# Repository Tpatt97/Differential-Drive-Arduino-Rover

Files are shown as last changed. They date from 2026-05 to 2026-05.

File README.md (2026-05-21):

# Differential-Drive-Arduino-Rover
Custom differential-drive rover featuring a fully 3D printed chassis, PWM motor control, joystick steering, and live OLED telemetry using Arduino.

Rover Demo

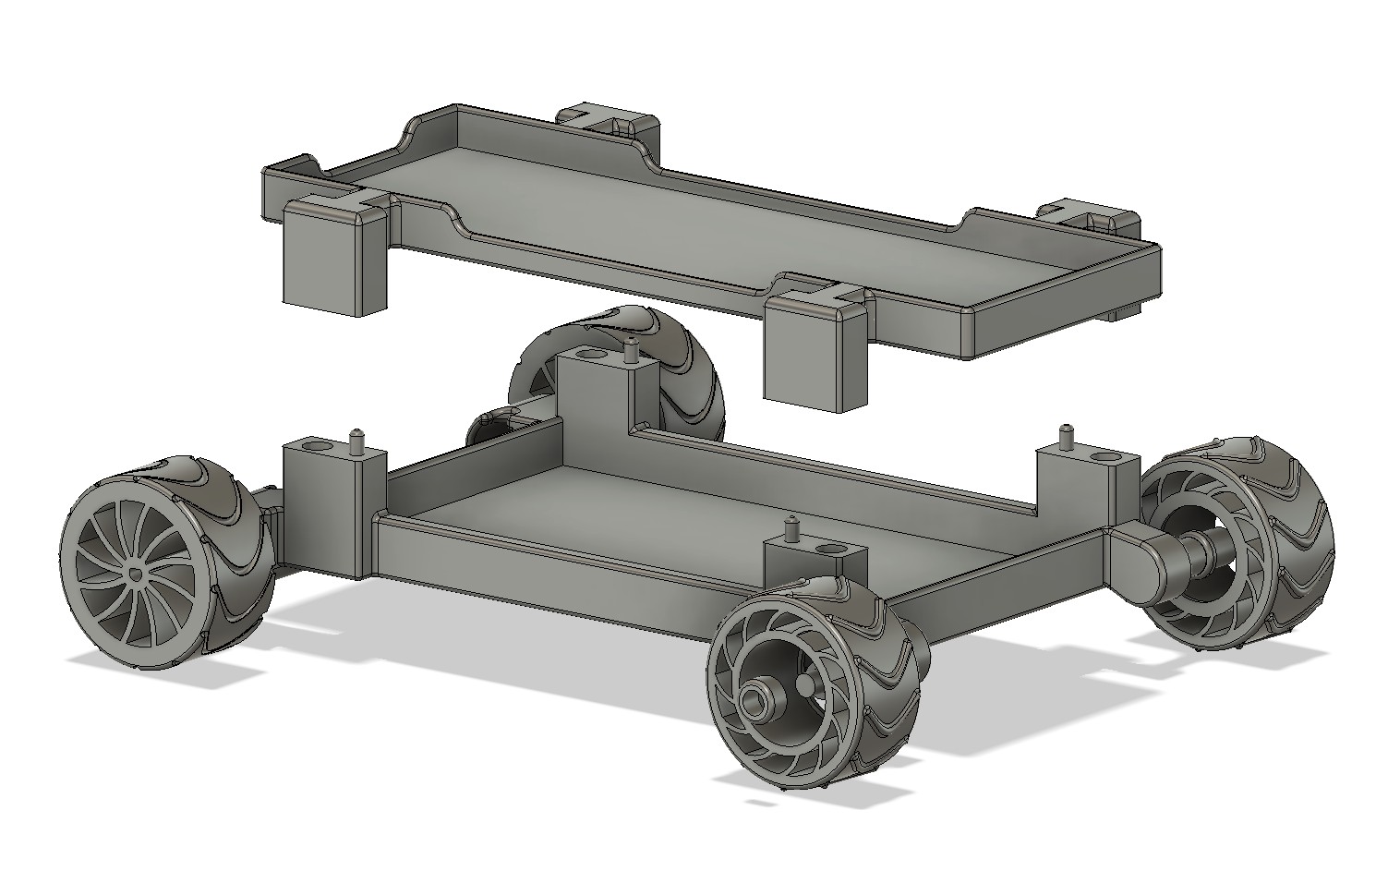
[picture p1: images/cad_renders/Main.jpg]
HERO Image


---

## Project Overview

This project is a custom-built Arduino rover platform designed and fabricated from the ground up using Fusion 360, embedded motor control, and additive manufacturing techniques.

The rover uses a differential steering drivetrain powered by dual DC gear motors controlled through PWM transistor stages. Real-time telemetry is displayed through an onboard I2C OLED display while joystick input provides proportional throttle and steering control.

Rover Demo

The project combines:

- Mechanical CAD design
- 3D printing
- Embedded systems
- Power electronics
- Differential drive control
- Real-time telemetry systems
  
---

## Features 

- Fully custom 3D printed chassis and drivetrain
- Differential steering control
- Dual PWM-controlled DC motors
- Analog joystick input system
- Live OLED telemetry display
- Custom Fusion 360 wheel and tread design
- Modular upper electronics tray
- Embedded Arduino firmware
- Real-time motor output calculations

---

## Media Section

### Final Rover Assembly
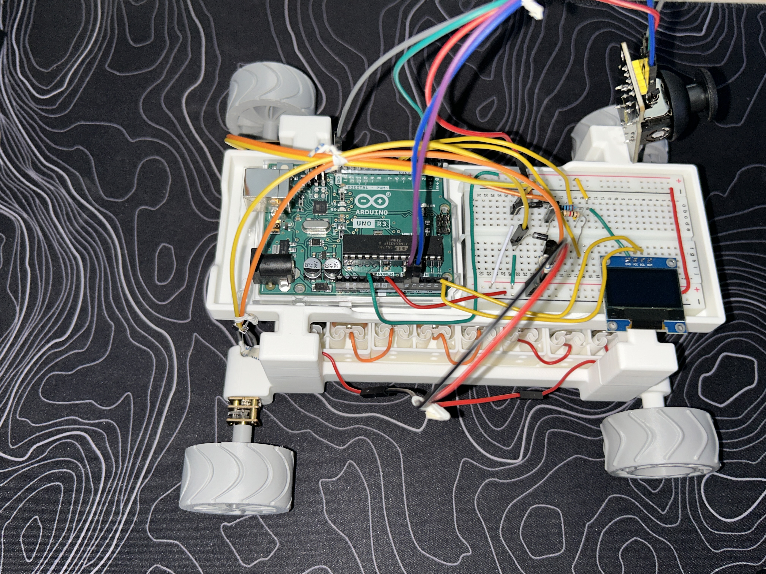
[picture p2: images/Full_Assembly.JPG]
Top View


### Lower Chassis
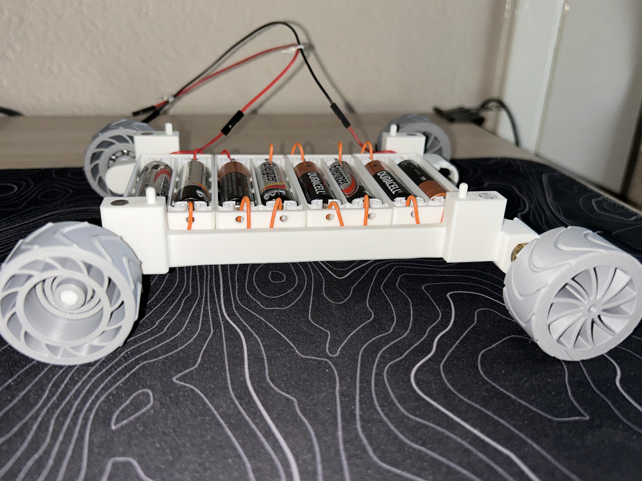
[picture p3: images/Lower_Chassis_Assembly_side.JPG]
Lower Chassis


### Upper Electronics Tray
Upper Electronics Tray

### Modular Assembly

- The upper electronics tray was designed as a removable modular assembly using alignment pins and recessed magnetic attachment points integrated directly into the lower chassis and upper tray. This architecture allowed rapid access to the battery bank while maintaining repeatable alignment and secure retention of the embedded electronics during both battery replacement and rover operation.
  
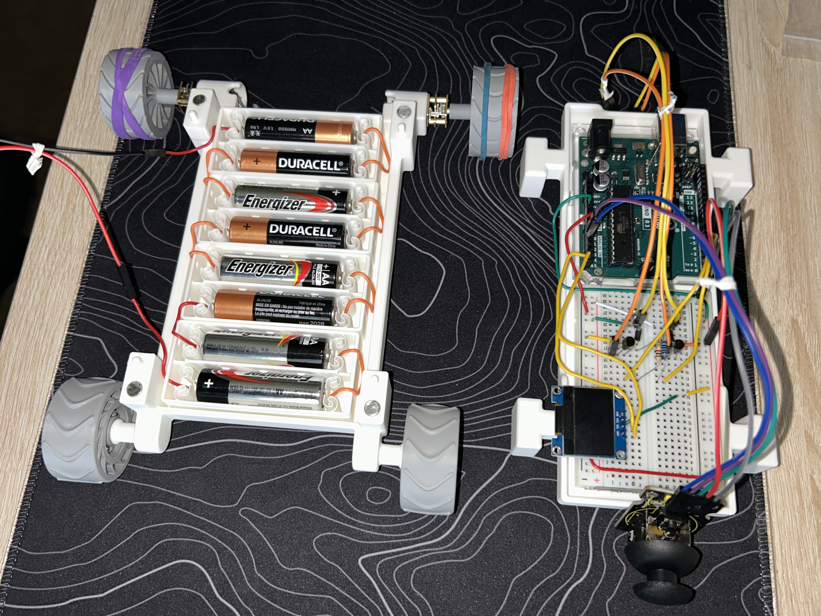
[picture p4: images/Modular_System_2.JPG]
Modular System


### OLED Telemetry
OLED Telemetry

### Drivetrain Closeup
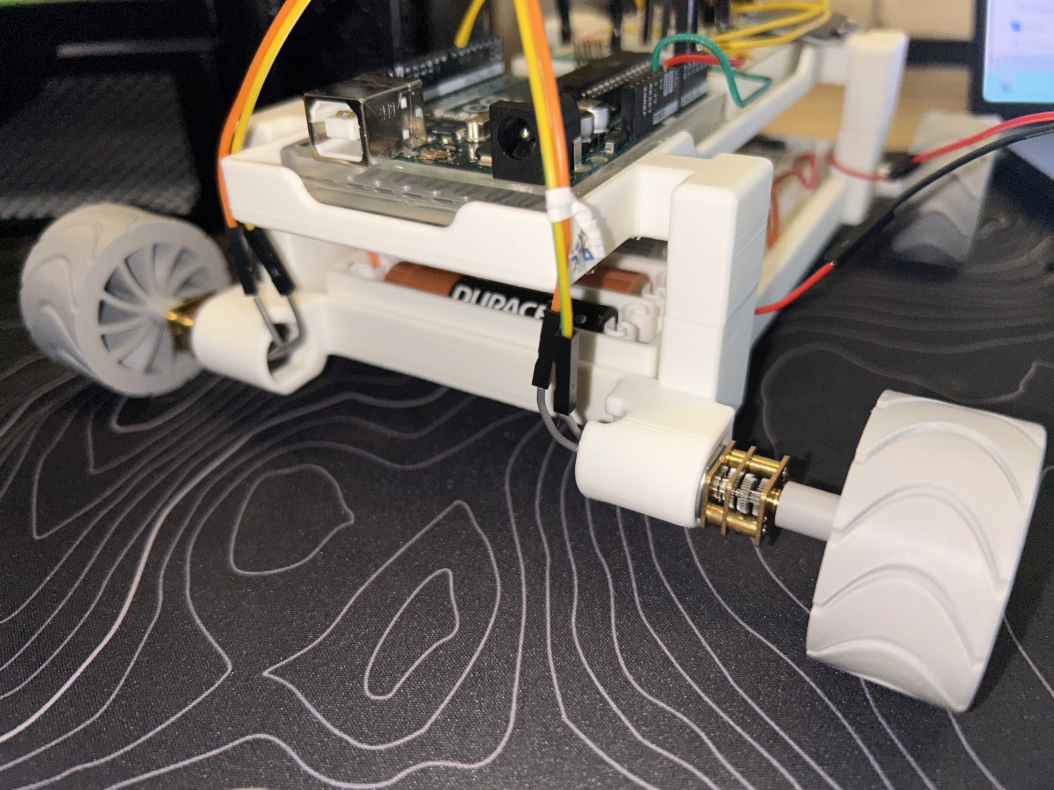
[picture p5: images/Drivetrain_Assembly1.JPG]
Wheel Closeup 1

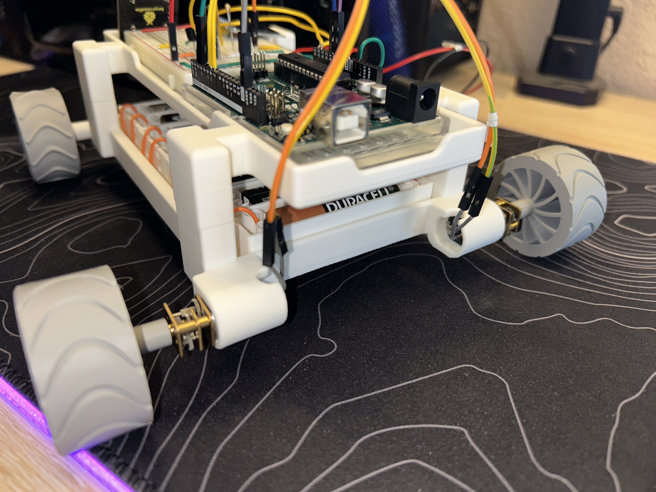
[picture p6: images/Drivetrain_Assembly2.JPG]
Wheel Closeup


---

## CAD Design Section

All mechanical components were designed in Autodesk Fusion 360.

Key design objectives included:

- Modular assembly
- Compact drivetrain packaging
- Easy battery integration
- Printable geometry optimization
- Lightweight wheel construction
- Integrated wiring/electronics tray

### Fusion 360 Renders

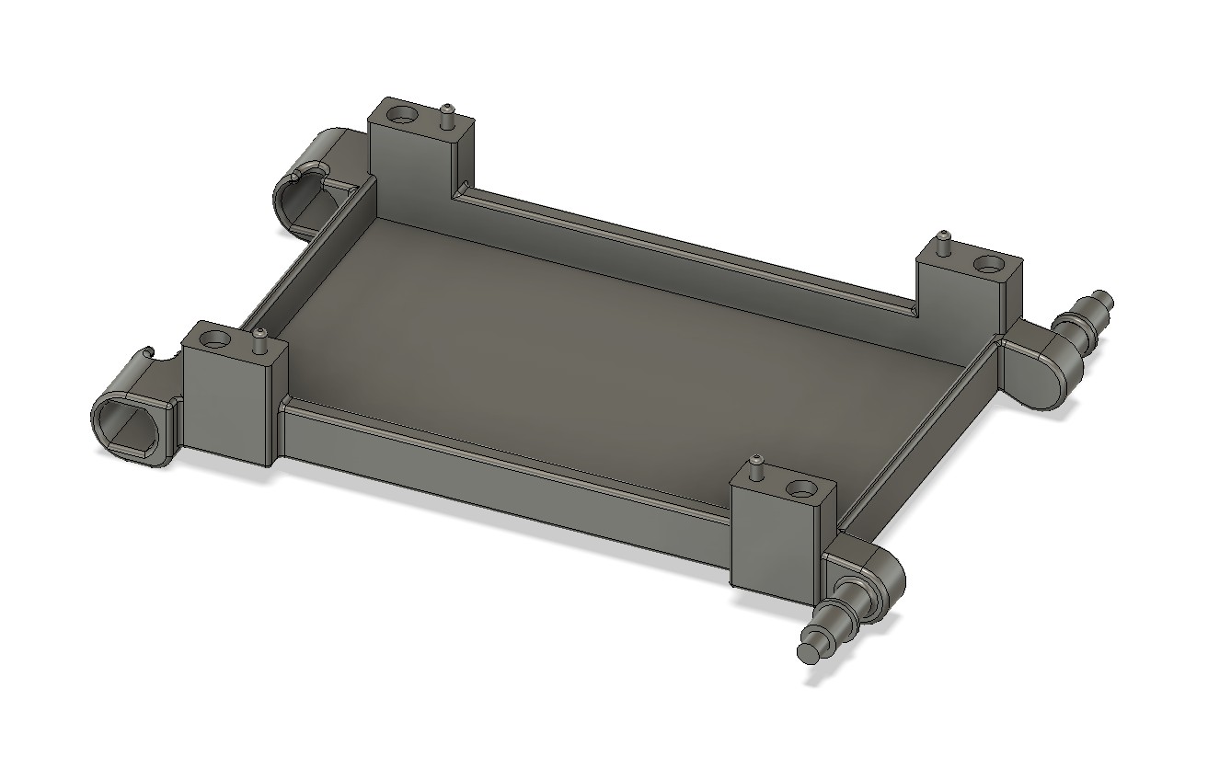
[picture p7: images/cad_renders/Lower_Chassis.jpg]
Lower Chassis


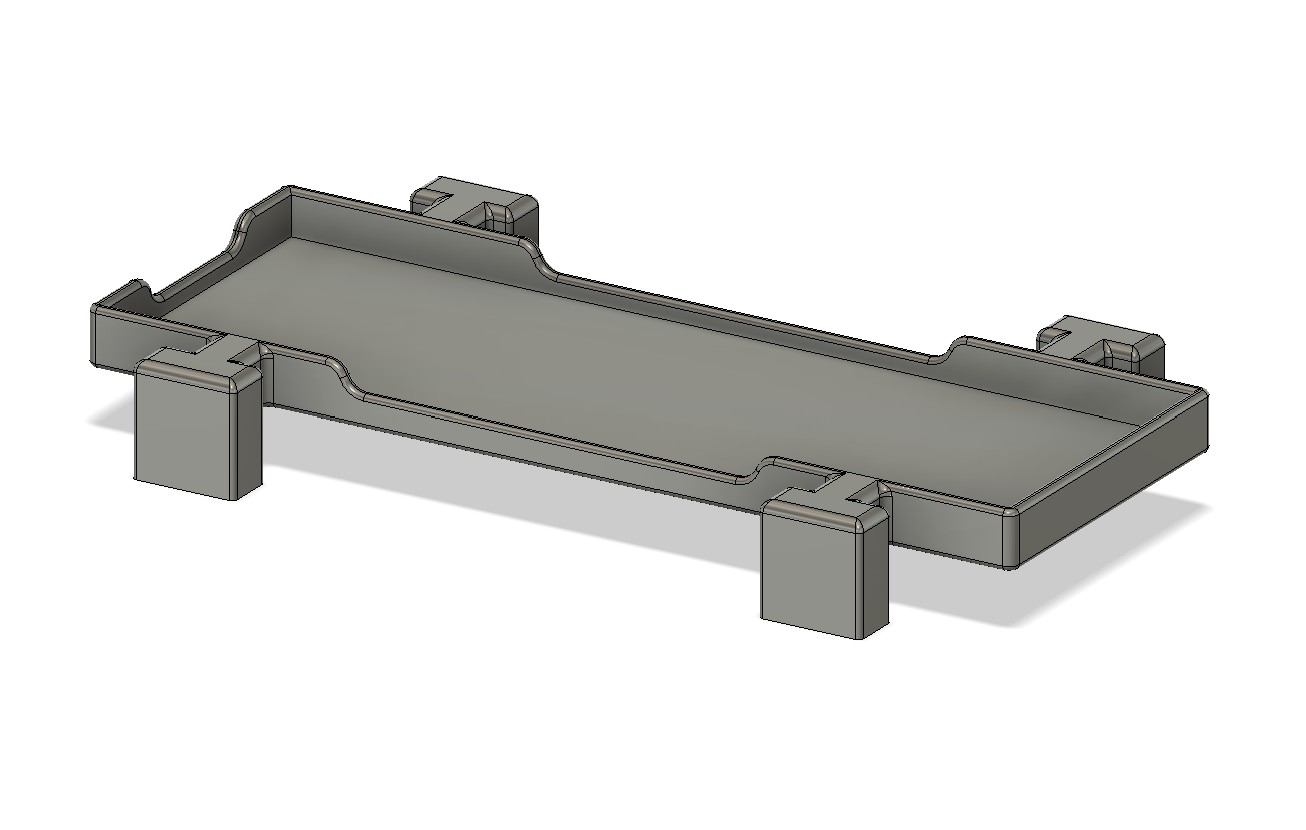
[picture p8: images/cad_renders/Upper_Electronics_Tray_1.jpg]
Upper Electroncis Tray 1


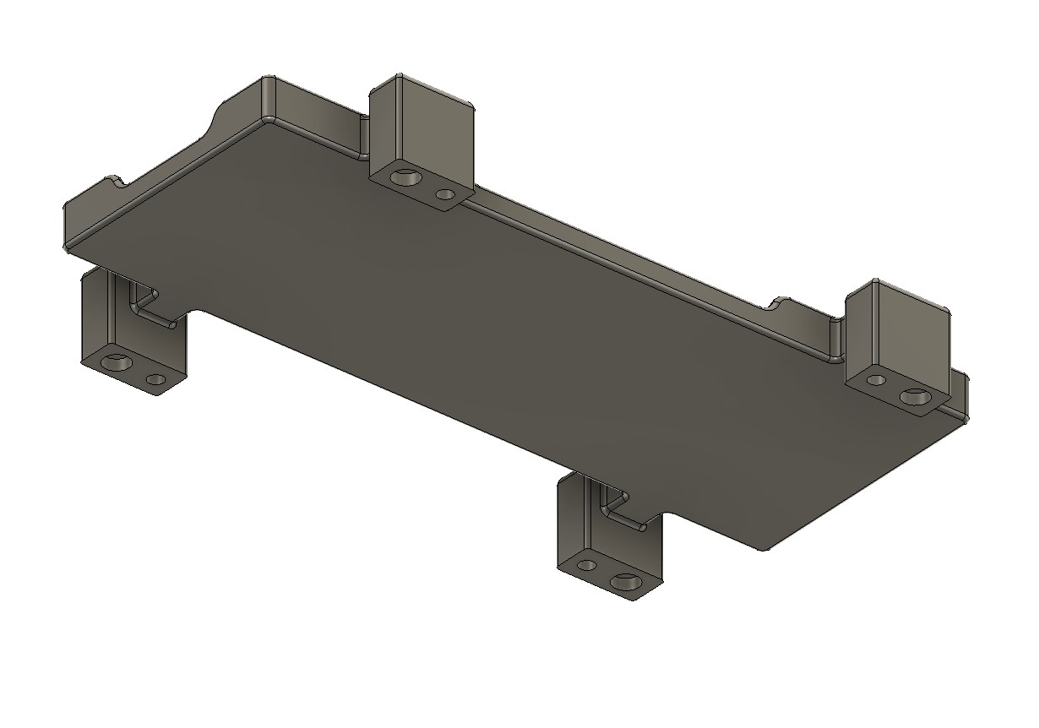
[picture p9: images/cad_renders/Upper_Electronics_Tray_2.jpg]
Upper Electroncis Tray 2


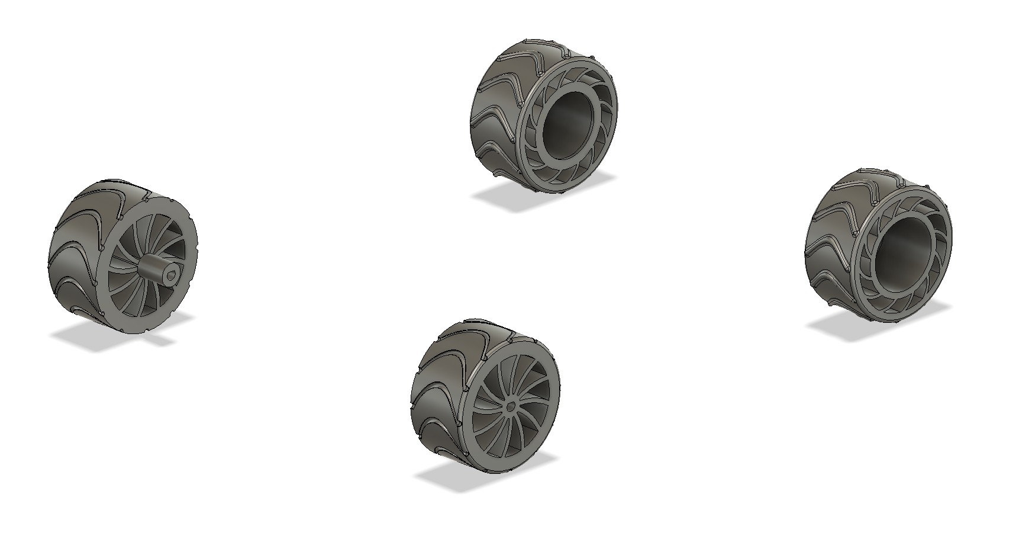
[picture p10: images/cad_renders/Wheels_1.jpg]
Wheel Design - All


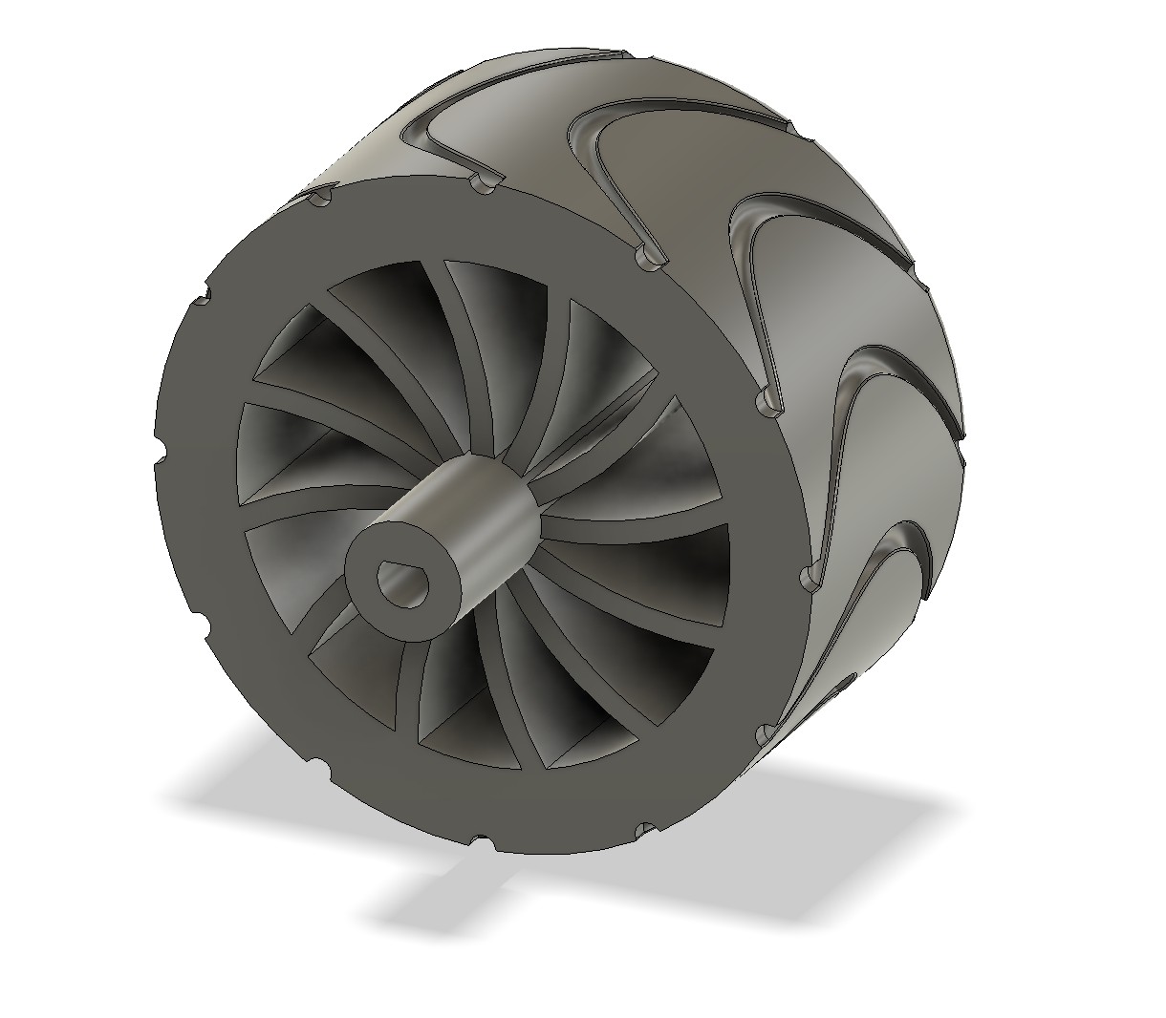
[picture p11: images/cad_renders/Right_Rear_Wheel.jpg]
Right Rear Wheel


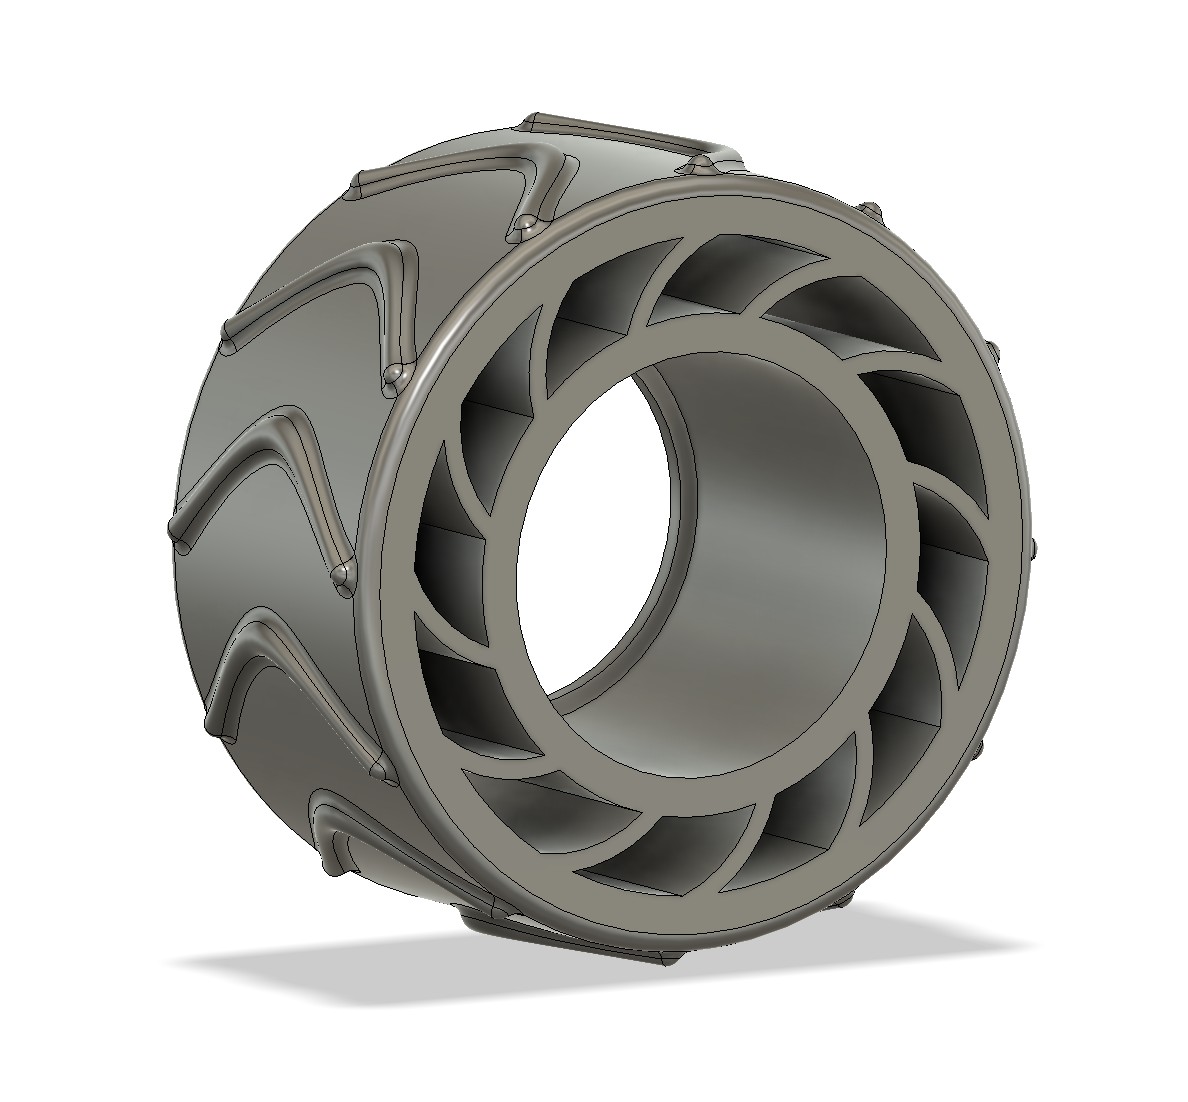
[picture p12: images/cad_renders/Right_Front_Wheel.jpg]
Right Front Wheel


---

## Electronics Architecture

- The rover uses differential steering driven by two independently PWM-controlled DC motors. Each motor is switched using a dedicated 2N2222 transistor stage with flyback diode protection. A joystick module provides analog steering/throttle input while an SSD1306 I2C OLED provides live telemetry feedback.

- The rover uses a dual-motor PWM drivetrain architecture controlled through an Arduino UNO.

Each motor is independently driven through a dedicated 2N2222 transistor stage with flyback diode protection.

### System Components

- Arduino UNO
- 2x 12V DC gear motors
- 2x 2N2222 NPN transistors
- 2x flyback diodes
- SSD1306 I2C OLED display
- Analog joystick module
- 8x AA battery pack

### Wiring Diagram

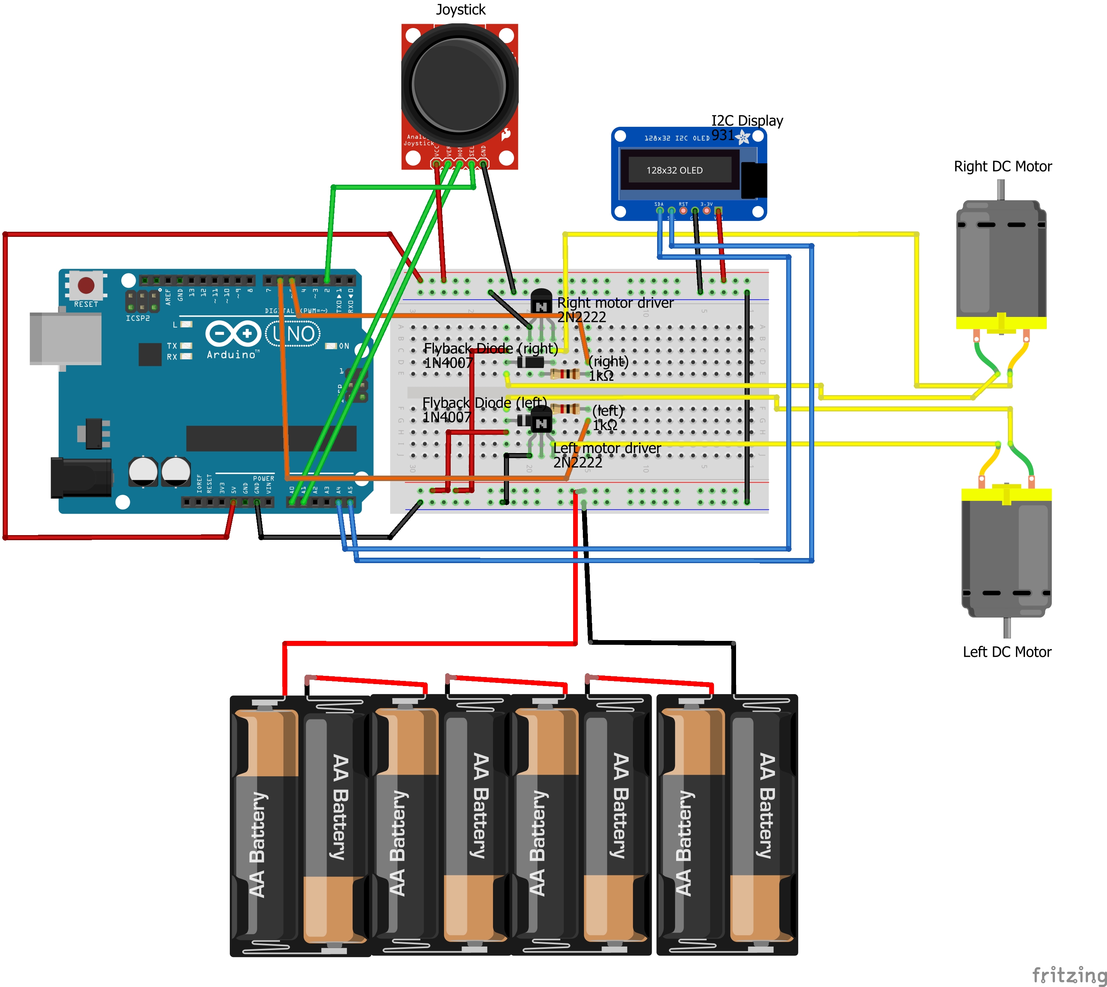
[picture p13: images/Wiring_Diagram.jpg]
Wiring Diagram


---

## Firmware Features

The firmware implements:

- Analog joystick processing
- Differential steering calculations
- PWM motor control
- OLED telemetry output
- Deadzone filtering
- Real-time motor percentage calculations

### Telemetry Output

Current telemetry includes:

- Throttle %
- Steering bias %
- Left motor output %
- Right motor output %

---

## Challenges & Limitations

Several engineering and fabrication challenges were encountered during development:

### Wheel Traction

Initial PLA wheel prototypes provided insufficient traction on smooth surfaces. Removable rubber traction bands were later added to the driven wheels to improve drivetrain grip and vehicle stability.

### 3D Printing Support Failures

Large chassis overhangs initially caused support instability and print separation issues. Print orientation, support interface settings, and cooling parameters were iteratively adjusted to improve reliability.

### Fusion 360 Assembly References

Assembly reference and context-linking issues occasionally caused export failures and broken dependencies between components. Workflow adjustments and isolated exports were used to stabilize the design pipeline.

### OLED Debugging

I2C display initialization and address conflicts required multiple rounds of firmware debugging and wiring verification before successful telemetry integration.

---

## Future Improvements 

Planned future upgrades include:

- H-bridge motor drivers
- MOSFET-based power stages
- Bidirectional motor control
- ESP32 wireless control
- Battery voltage monitoring
- Wheel encoders
- Closed-loop speed control
- Suspension system
- Custom PCB integration

---

## Author

Designed, fabricated, programmed, and documented by Trevor Patterson

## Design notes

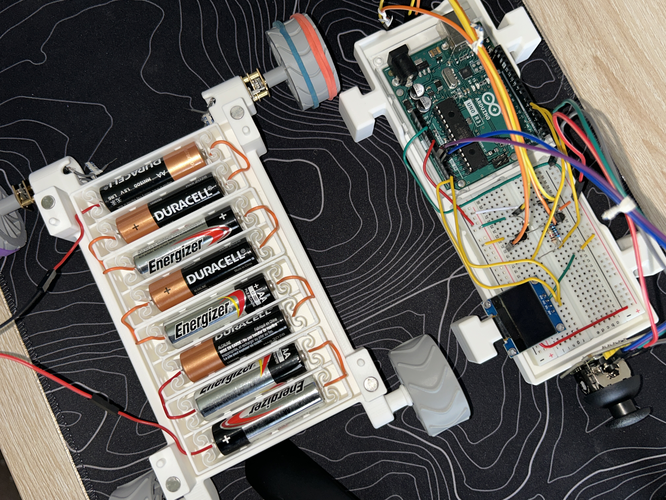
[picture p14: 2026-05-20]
images/Modular_System.JPG

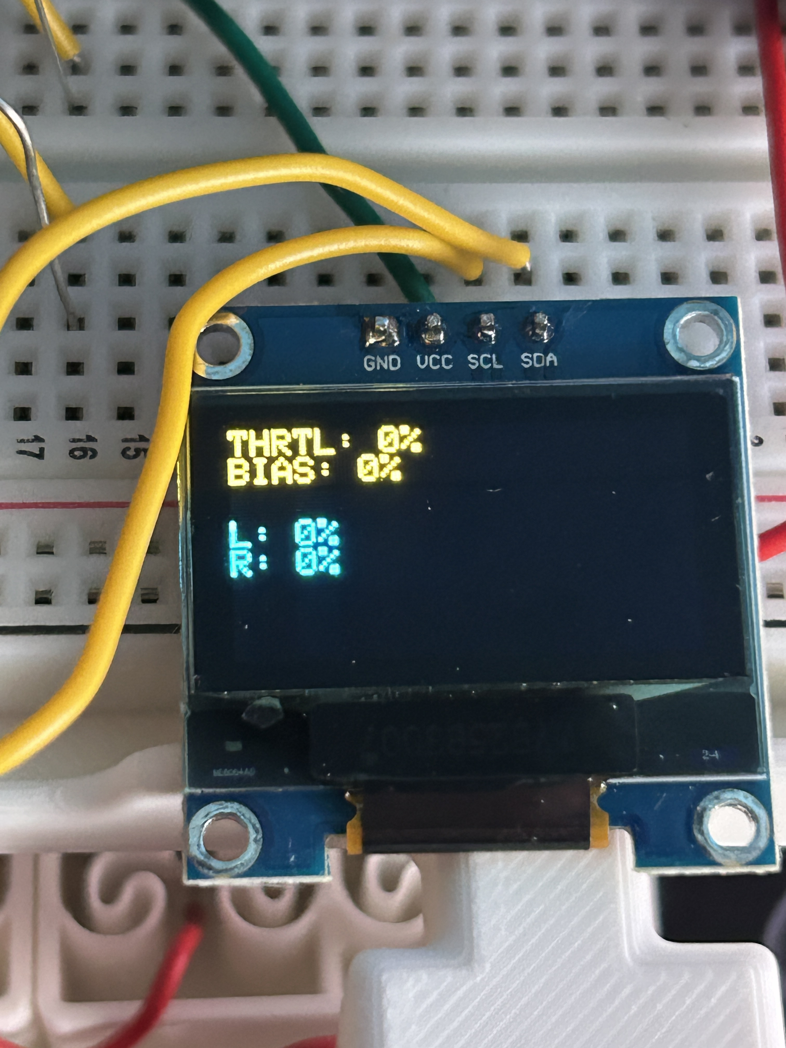
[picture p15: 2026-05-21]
images/OLED_Telemetry.JPG

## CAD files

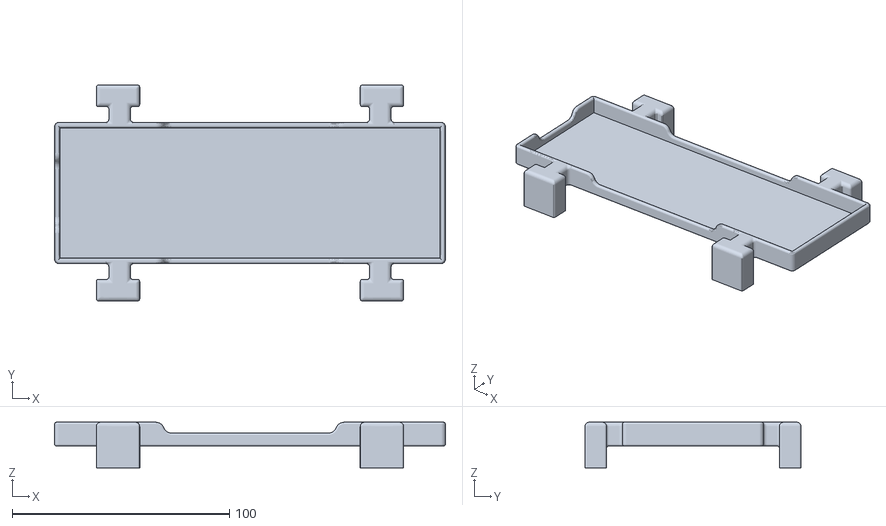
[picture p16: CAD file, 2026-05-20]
cad/Upper Tray v2.stl
180.0 x 99.5 x 21.0

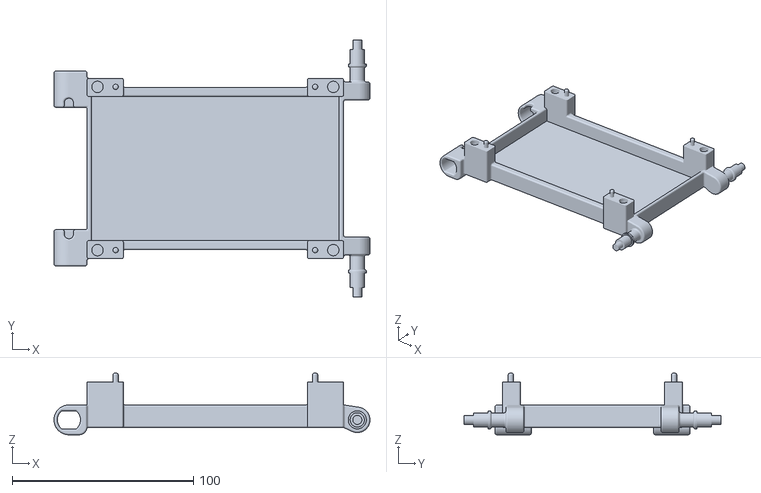
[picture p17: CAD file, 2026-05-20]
cad/Lower Chassis v3.stl
174.2 x 141.5 x 34.0

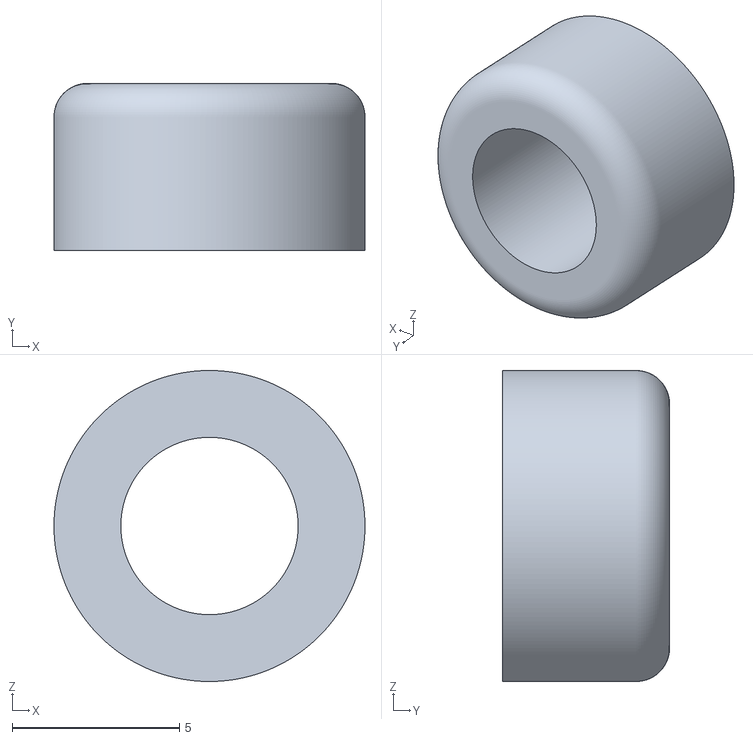
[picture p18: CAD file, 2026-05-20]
cad/Front Axel End Cap.stl
9.30 x 5.00 x 9.30

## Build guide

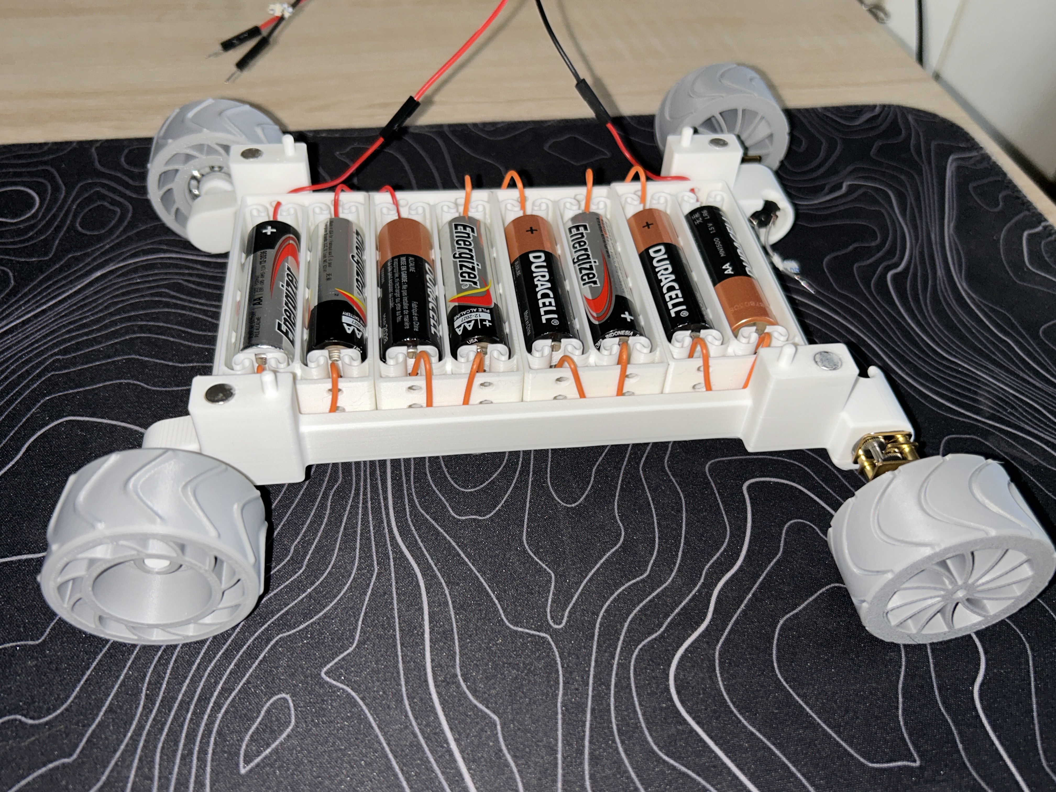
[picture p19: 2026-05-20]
images/Lower_Chassis_Assembly.JPG

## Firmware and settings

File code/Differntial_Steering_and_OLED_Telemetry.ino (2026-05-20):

//Including Libraries//
#include <Wire.h>
#include <Adafruit_GFX.h>
#include <Adafruit_SSD1306.h>

//OLED Definitions//
#define SCREEN_WIDTH 128
#define SCREEN_HEIGHT 64
#define OLED_RESET -1

Adafruit_SSD1306 display(SCREEN_WIDTH, SCREEN_HEIGHT, &Wire, OLED_RESET);


// Establishment of Variables //
int xValue;
int yValue;

int throttle;
int steering;

int leftMotorSpeed;
int rightMotorSpeed;

int leftMotorPin = 5;
int rightMotorPin = 6;


void setup() {

  pinMode(leftMotorPin, OUTPUT);
  pinMode(rightMotorPin, OUTPUT);

  Serial.begin(9600);

  //OLED SETUP//
  if(!display.begin(SSD1306_SWITCHCAPVCC, 0x3C)) {
    Serial.println("OLED failed");
    for(;;);
  }

  display.clearDisplay();

  display.setTextSize(1);
  display.setTextColor(SSD1306_WHITE);

  display.setCursor(0,0);
  display.println("ROVER ONLINE");

  display.display();

  delay(2000);

}

void loop() {
  // Read Joystick //
  xValue = analogRead(A0);
  yValue = analogRead(A1);

  // Convert Joystick values //
  throttle = map(yValue, 0, 1023, -255, 255);
  steering = map(xValue, 0, 1023, -255, 255);

  // Deadzone //
  if (abs(throttle) < 20) {
    throttle = 0;
  }

  if (abs(steering) < 20) {
    steering = 0;
  }

  // Differential steering math //
  leftMotorSpeed = throttle + steering;
  rightMotorSpeed = throttle - steering;

  // Constrain values //
  leftMotorSpeed = constrain(leftMotorSpeed, 0, 255);
  rightMotorSpeed = constrain(rightMotorSpeed, 0, 255);

  // Output PWM //
  analogWrite(leftMotorPin, leftMotorSpeed);
  analogWrite(rightMotorPin, rightMotorSpeed);

  // Debug //
  Serial.print("Throttle: ");
  Serial.print(throttle);

  Serial.print("  Steering: ");
  Serial.print(steering);

  Serial.print("  Left: ");
  Serial.print(leftMotorSpeed);

  Serial.print("  Right: ");
  Serial.println(rightMotorSpeed);


  // OLED Telemetry //
  int throttlePercent = map(abs(throttle), 0, 255, 0, 100);
  int biasPercent = map(steering, -255, 255, -100, 100);
  int leftPercent = map(leftMotorSpeed, 0, 255, 0, 100);
  int rightPercent = map(rightMotorSpeed, 0, 255, 0, 100);

  display.clearDisplay();
  display.setCursor(0,0);

  display.print("THRTL: ");
  display.print(throttlePercent);
  display.println("%");

  display.print("BIAS: ");
  display.print(biasPercent);
  display.println("%");

  display.println();

  display.print("L: ");
  display.print(leftPercent);
  display.println("%");

  display.print("R: ");
  display.print(rightPercent);
  display.println("%");

  display.display();



  delay(200);
}

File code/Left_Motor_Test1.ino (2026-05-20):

int yValue;
int motorSpeed;

int motorPin = 5;

void setup() {

  pinMode(motorPin, OUTPUT);

  Serial.begin(9600);
}

void loop() {

  yValue = analogRead(A1);

  //Map joystick range to PWM range
  motorSpeed = map(yValue, 512, 1023, 0 , 255);

  //Prevent negative values
  if (motorSpeed < 0) {
    motorSpeed = 0;
  }

  analogWrite(motorPin, motorSpeed);

  Serial.print("Y: ");
  Serial.print(yValue);

  Serial.print("PWM: ");
  Serial.println(motorSpeed);

  delay(50);

}

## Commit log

2026-05-20 Create cad folder
2026-05-20 Added .STL files to CAD folder
    [Front Axel End Cap.stl, Lower Chassis v3.stl, Upper Tray v2.stl]
2026-05-20 Rename IMG_8860.JPG to Full Assembly
2026-05-20 Added Wiring Diagram to Images Directory
2026-05-21 Added CAD renders to the Images Directory
2026-05-21 Added CAD Renders into Images Directory
2026-05-21 Added CAD renders to README
2026-05-21 Added Diff Steering .GIF to Media Directory
